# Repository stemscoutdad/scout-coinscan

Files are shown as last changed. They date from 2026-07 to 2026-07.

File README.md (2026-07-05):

SCOUT CoinScan logo

# SCOUT CoinScan

**Sorting Coins Optically with UV Technology** — an open-source coin identification, grading-assist, and sorting machine printed on the Snapmaker U1.

Entered in the **Snapmaker Innovation Fund · Open Competition Phase 1** (June–September 2026).

Repo: https://github.com/stemscoutdad/scout-coinscan

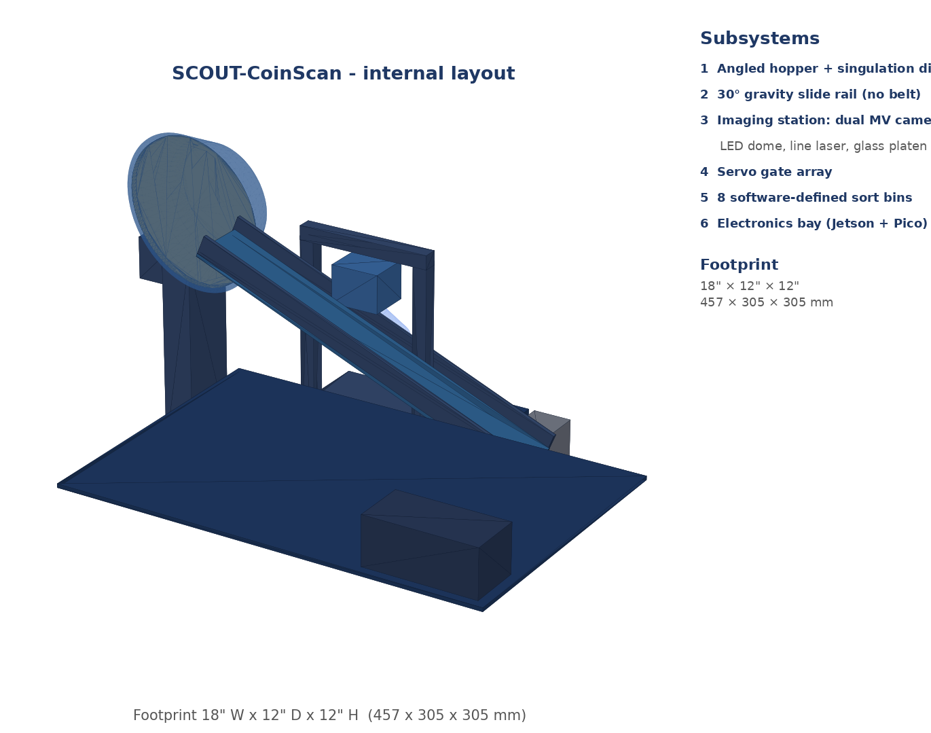
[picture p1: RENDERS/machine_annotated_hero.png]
SCOUT-CoinScan concept rendering


*Concept rendering — 18″ W × 12″ D × 12″ H envelope. Gravity-fed hopper → dual-camera imaging station → software-defined sort bins.*

---

## What it does

Feed it a jar of mixed coins. A U1-printed singulation disk presents one coin at a time onto a gravity slide rail — no conveyor, no belt. Each coin stops on a glass platen between two cameras and is imaged on both faces simultaneously with a multispectral capture sequence: cross-polarized white light, four-direction photometric-stereo sweeps, 470/630/850 nm and 365 nm UV channels, and a swept 650 nm line-laser height profile. On-device ML (NVIDIA Jetson Orin NX 16 GB, 157 TOPS) identifies the coin, reads the date and mint mark, flags doubled dies, repunched marks, silver composition, cleaning and alteration, and estimates a condition-assist score. A servo then steers the coin into one of eight bins.

**The sort is pure software.** Sort by denomination today; by decade, mint mark, or silver content tomorrow — one config change, zero reprinting. The vision system also closes the loop on mechanical singulation: side-by-side double feeds are detected optically and recirculated to the hopper automatically.

## Why the U1 specifically

- **Co-printed TPU-on-PETG mechanisms** — hopper double-wiper, brake brushes, gate-paddle facings, V-stop pads, deflector lip: flexible features printed in place, no assembly.
- **Color as function** — multicolor drop-in calibration target at the coin plane, color-coded bins, translucent diffuser ring on an opaque lighting dome.
- **Bed finish as bearing surface** — rail sections printed face-down so the U1's bed finish becomes the coin's low-friction slide surface.

## Repository layout

```
CAD/        STEP solids + DXF face drawings (disk, platen, brackets, calibration target)
HARDWARE/   Master BOM (sourced part numbers + links), wiring notes
DOCS/       One-pager, Jetson↔Pico protocol spec, build guide (in progress)
FIRMWARE/   RP2040 Pico real-time controller — coming with the July build
SOFTWARE/   Jetson vision pipeline — coming with the July build
```

## Build tiers

| | Flagship | Budget |
|---|---|---|
| Compute | Jetson Orin NX 16 GB dev kit | Jetson Orin Nano Super 8 GB |
| Cameras | 2× 1″ Sony IMX283 20 MP (USB 3.0) | 2× IMX477 HQ 12.3 MP (CSI) |
| Focus | Motorized AF + focus stacking | Fixed focus |
| Est. cost | ~$1,650 | ~$900 |

## Safety

365 nm UV and the line laser are enclosed behind an acrylic-windowed panel with a lid interlock wired in hardware series with both supplies.

## Status

- [x] Architecture, optics geometry, sourced BOM, transport design, control protocol
- [x] Parametric CAD: singulation disk, platen frame, bracket set, calibration target
- [ ] Imaging station build + capture pipeline (July milestone)
- [ ] Transport + gate integration, classifier training (August)
- [ ] Documentation, demo video, release (early September)

## License

MIT — see [LICENSE](LICENSE).

---

*Project lead: Benjamin Flores (Chula Vista, CA) — machining/fabrication, electronics, and numismatics. This build also anchors STEM programming for a local Scouts BSA troop maker initiative. If this project is useful or interesting to you, a ⭐ helps it in the Innovation Fund community vote!*

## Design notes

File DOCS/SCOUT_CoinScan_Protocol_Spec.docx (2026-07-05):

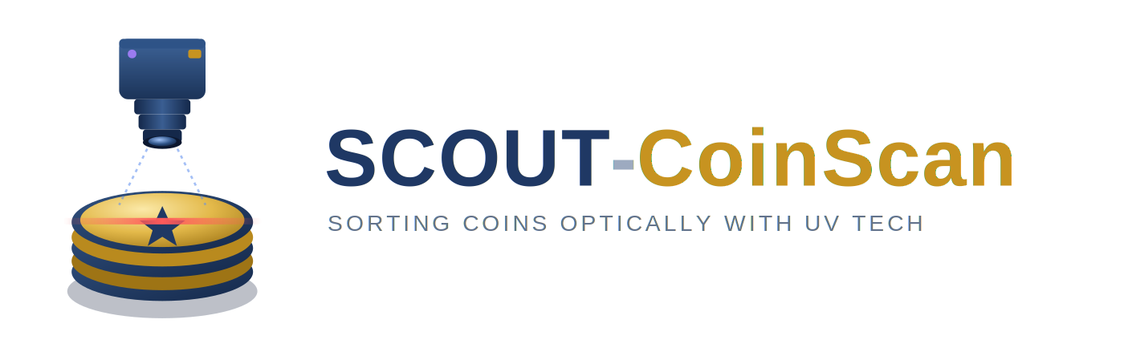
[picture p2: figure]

SCOUT CoinScan — Jetson ↔ Pico Command Protocol

v0.1 · USB CDC serial · 115200 baud 8N1 · ASCII lines terminated \n

The Jetson (host) is the master and issues commands; the RP2040 Pico (controller) executes real-time motion, lighting, and sensor tasks and replies. Fields are space-separated. Every command carries an integer sequence id so replies can be matched.

# Line format

Host → Pico: <seq> <CMD> [args...]

Pico → Host: <seq> OK [data...] // success

<seq> ERR <code> <msg> // failure

EVT <name> [data...] // asynchronous, no seq

The Pico echoes the seq it received. Events (EVT) are unsolicited — beam breaks, faults, interlock trips — and carry no seq.

# Commands

CMD | Args | Action | Reply
PING | — | Liveness check | OK <fw_version>
HOME | — | Home Z-stage, center V-stop, paddles flat | OK when settled
FEED | — | Index singulation disk 90°, present next coin | OK or ERR JAM
ZMOVE | <µm> | Absolute Z-stage move (0 = platen focus datum) | OK <pos_um>
ZSWEEP | <start> <step> <n> | Move + EVT FOCUSPT at each stop for AF | OK after last
LIGHT | <ch> <pct> | Set one lighting channel | OK
CAPSEQ | <preset> | Run stored light sequence; EVT FRAME per state | OK after sequence
LASER | <0|1> | Line laser off/on (interlock-gated) | OK or ERR INTERLOCK
LSWEEP | <deg0> <deg1> <ms> | Pivot laser across coin; EVT LASERPT per step | OK
VSTOP | <0|1> | 0 = hold coin, 1 = retract/release | OK
GATE | <n> <0|1> | Paddle n (1–8): 0 flat, 1 deflect | OK
SORT | <bin> | Set paddle, retract V-stop, watch rail-end beam | OK <bin> or ERR MISS
STATUS | — | Dump sensor + position state | OK <json>
ESTOP | — | All motion halt, laser+UV off, paddles flat | OK

# Lighting channels (LIGHT)

0 white ring · 1 UV 365 nm · 2 blue 470 nm · 3 red 630 nm · 4 IR 850 nm · 5..8 white quadrants N/E/S/W (photometric stereo). pct = 0–100.

# Capture presets (CAPSEQ)

- 1 FAST — cross-polarized white only (bulk sorting)
- 2 FULL — white → quad N/E/S/W → blue → red → IR → UV, EVT FRAME at each (deep scan)
- 3 CALIB — white flat field for px/mm + white balance

# Events

EVT | Data | Meaning
BEAM | <id> <0|1> | Break-beam edge (1 entry, 2 pre-gate, 3 rail-end)
FOCUSPT | <pos_um> | Z-stage settled at sweep stop; host computes sharpness
FRAME | <tag> | Lights set for <tag>; host grabs both cameras now
LASERPT | <deg> | Laser at angle; host grabs top-cam frame
MISS | <bin> | Rail-end beam fired after SORT — coin missed its gate
JAM | <where> | Disk stall or beam-timeout
INTERLOCK | <0|1> | Lid opened (1) / closed (0); laser+UV force-off on open
FAULT | <code> | Driver fault (stepper OT, servo brownout)

# Typical single-coin cycle (host orchestration)

1. FEED — coin lands; EVT BEAM 1 1 fires when it reaches the station
2. VSTOP 0 (hold) — coin self-centers on the V
3. ZSWEEP → collect EVT FOCUSPT, host finds peak, ZMOVE <peak>
4. CAPSEQ 2 FULL → host grabs frame pairs on each EVT FRAME
5. LSWEEP → host builds height map from EVT LASERPT frames
6. Host runs vision → decides bin
7. SORT <bin> → V-stop retracts, coin routes; ERR MISS if rail-end beam trips
8. Paddle auto-returns flat; loop to 1 (next coin already staged)

# Safety invariants (enforced on the Pico, not the host)

- LASER 1 and UV (LIGHT 1 >0) are refused with ERR INTERLOCK whenever the lid switch is open; both are hardware-series-cut regardless.
- Any EVT INTERLOCK 1 immediately zeroes laser + UV channels on the Pico without waiting for the host.
- Watchdog: if no host line for 3 s during motion, the Pico executes ESTOP.

Design intent: the Pico guarantees timing and safety; the Jetson owns all vision and decisions. Keeping the split this clean is what lets each half be released and reused independently.

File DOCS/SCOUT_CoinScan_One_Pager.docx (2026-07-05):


SCOUT CoinScan

Sorting Coins Optically with UV Technology · Snapmaker Innovation Fund · Open Competition Phase 1 · June–September 2026

An open-source, U1-printed machine that identifies, inspects, and sorts coins by what they actually are — not just how big they are.


Concept rendering — 18″ W × 12″ D × 12″ H envelope. Gravity-fed hopper → imaging station → software-defined sort bins.

# What it does

Feed it a jar of mixed coins. A U1-printed singulation disk presents one coin at a time onto a gravity slide rail — no conveyor, no belt. Each coin stops on a glass platen between two cameras and is imaged on both faces simultaneously with a multispectral capture sequence: cross-polarized white light, four-direction photometric-stereo sweeps, 470 nm / 630 nm / 850 nm / 365 nm UV channels, and a swept 650 nm line-laser height profile. On-device ML (NVIDIA Jetson Orin NX 16 GB, 157 TOPS) identifies the coin, reads the date and mint mark, flags doubled dies, repunched marks, silver composition, cleaning and alteration, and estimates a condition-assist score. A servo then steers the coin into one of eight bins.

The sort is pure software. Sort by denomination today; by decade, mint mark, or silver content tomorrow — one config change, zero reprinting. The vision system also closes the loop on mechanical singulation: side-by-side double feeds are detected optically and recirculated to the hopper automatically.

# Why the U1 specifically

Nearly every structural, optical, and mechanical part is printed, and the design leans on the U1's four-toolhead system in ways single-material printers can't reproduce:

- Co-printed TPU-on-PETG mechanisms — hopper double-wiper, brake brushes, gate-paddle facings, V-stop pads, deflector lip: flexible features printed in place, no assembly.
- Color as function — a drop-in camera-calibration target printed in contrasting colors at the coin plane; color-coded bins; translucent diffuser ring on an opaque dome for the lighting module.
- Bed finish as bearing surface — rail sections printed face-down so the U1's bed finish becomes the coin's low-friction slide surface.

# Open-source deliverables

1. Full parametric CAD + STLs/3MFs for every printed part, with print orientation notes
2. Pico real-time firmware and Jetson vision pipeline (capture, classification, OCR, photometric stereo, laser profilometry)
3. Standalone reusable module: the multispectral inspection light — addressable, polarized, five-wavelength LED dome with printed diffuser, useful for any small-object inspection project
4. Documented budget build (Jetson Orin Nano 8 GB + dual IMX477, fixed focus, ~$900) alongside the flagship build (Orin NX 16 GB developer kit + dual 1″ IMX283 20 MP cameras + motorized focus-stacking stage, ~$1,650)
5. Build guide, calibration procedure, and a U1 multi-material design write-up covering the co-printing techniques used

# Technical depth highlights

- Photometric-stereo relief mapping for die-variety and error detection on a hobby-class budget
- UV-fluorescence detection of cleaning, PVC residue, and altered surfaces
- Laser-triangulation thickness/edge profiling as a third biometric against slugs and counterfeits
- Two-tier adaptive capture: fast pass for bulk, deep scan (focus stack + full spectral sequence) auto-triggered for coins the classifier flags as interesting
- Pre-positioned gate control: identification happens while the coin is parked, so every sort is a static ramp by the time the coin moves — one sensor detects any miss

# Safety

365 nm UV and the line laser are enclosed behind an acrylic-windowed panel with a lid interlock wired in hardware series with both supplies.

# Status & timeline (Phase 1)

- Now: architecture, optics geometry, full BOM with sourced part numbers, and transport design complete
- July: imaging station build + capture pipeline (standalone demo milestone)
- August: hopper/transport integration, gate array, classification training
- Early September: documentation, demo video, community release

Designed so each stage stands alone as a working, documented deliverable.

# The ask

We're requesting a sponsored U1 to develop and debug on — the design's co-printed TPU mechanisms and multicolor functional parts need on-machine iteration to tune. Project lead: Benjamin Flores (Chula Vista, CA) — machining/fabrication, electronics, and numismatics background; the project also anchors STEM programming for a local Scouts BSA troop's maker initiative.

Repo: https://github.com/stemscoutdad/scout-coinscan · Demo video: [link] · Discussion: Snapmaker forum thread [link]

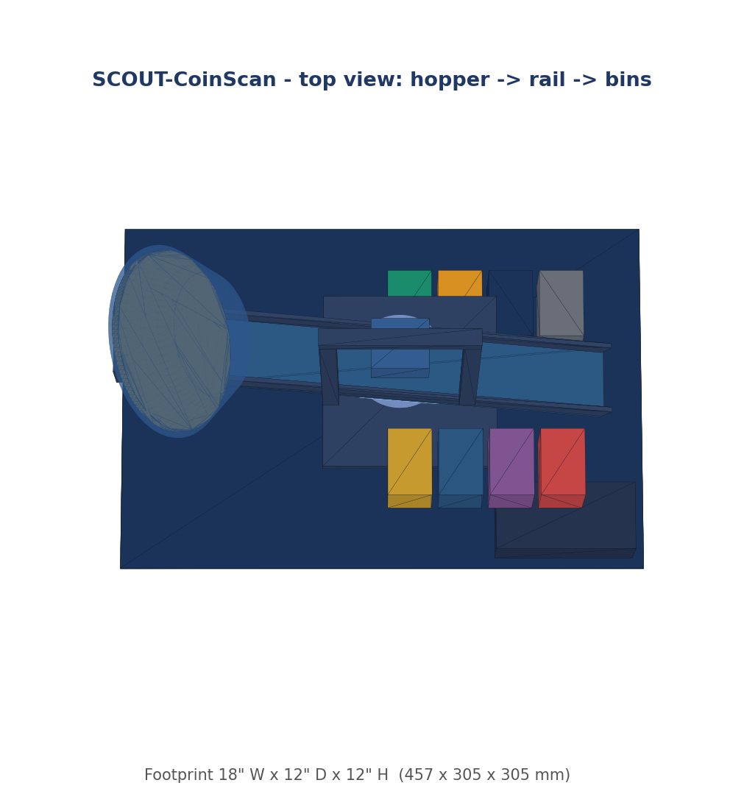
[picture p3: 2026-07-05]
RENDERS/machine_open_top.png

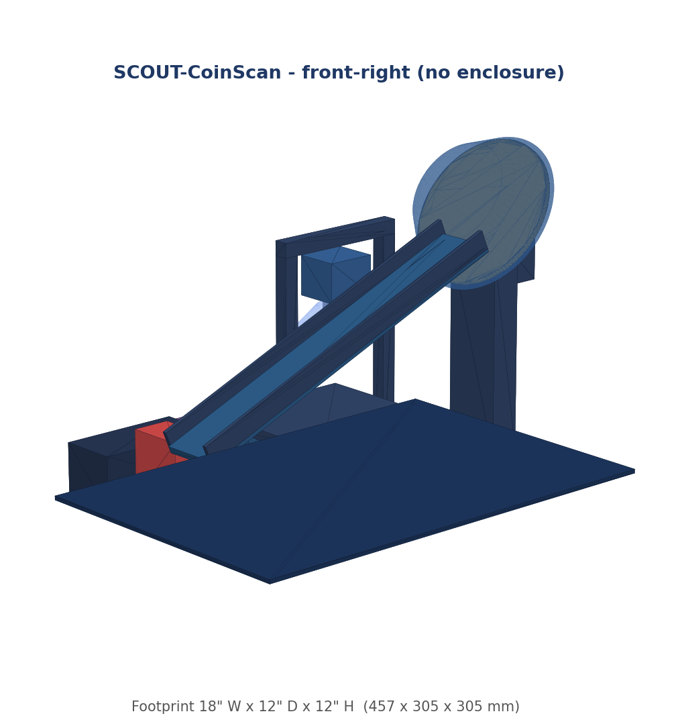
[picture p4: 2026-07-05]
RENDERS/machine_open_front.png

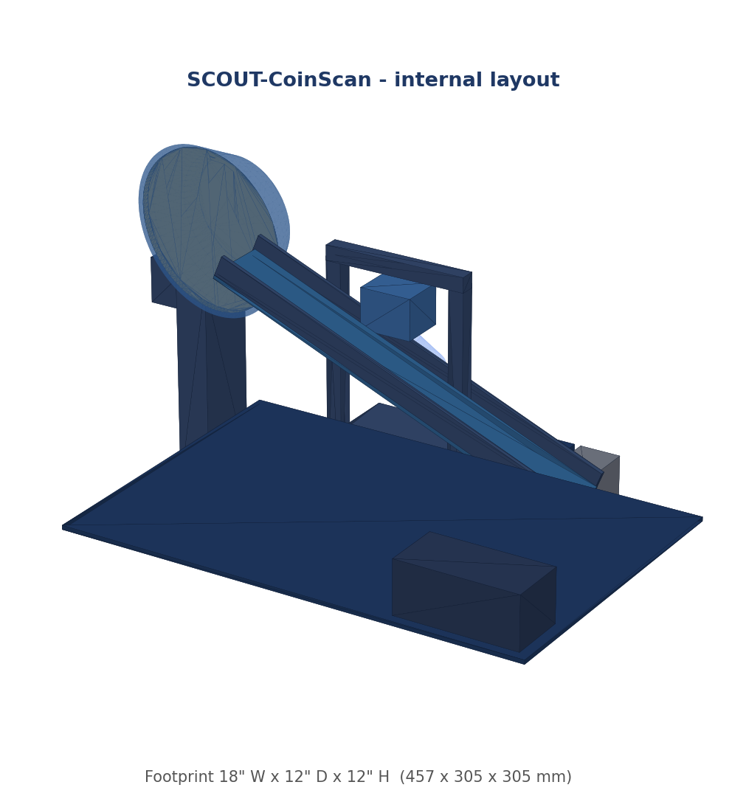
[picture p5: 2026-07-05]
RENDERS/machine_open_hero.png

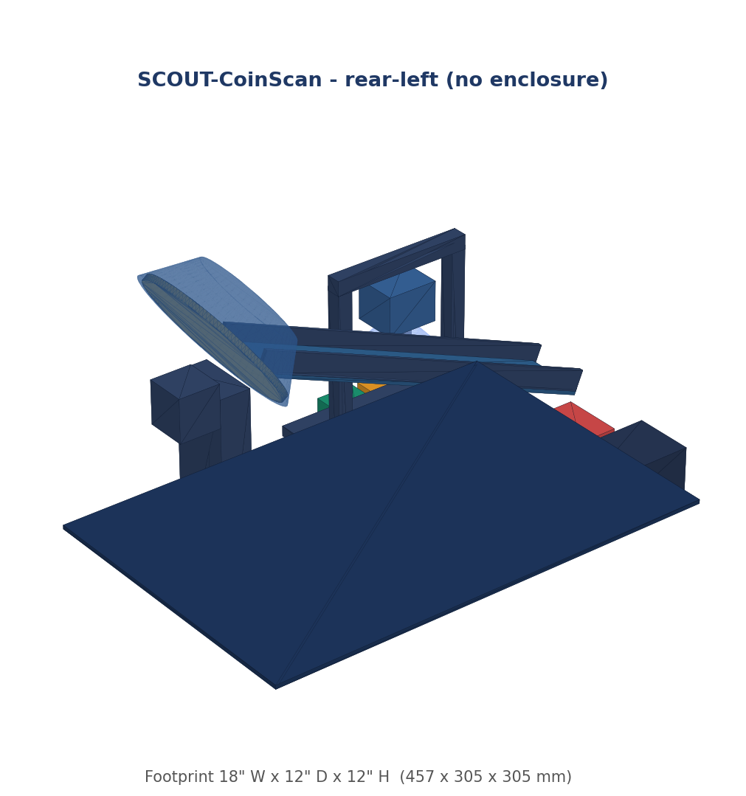
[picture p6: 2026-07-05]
RENDERS/machine_open_rear.png

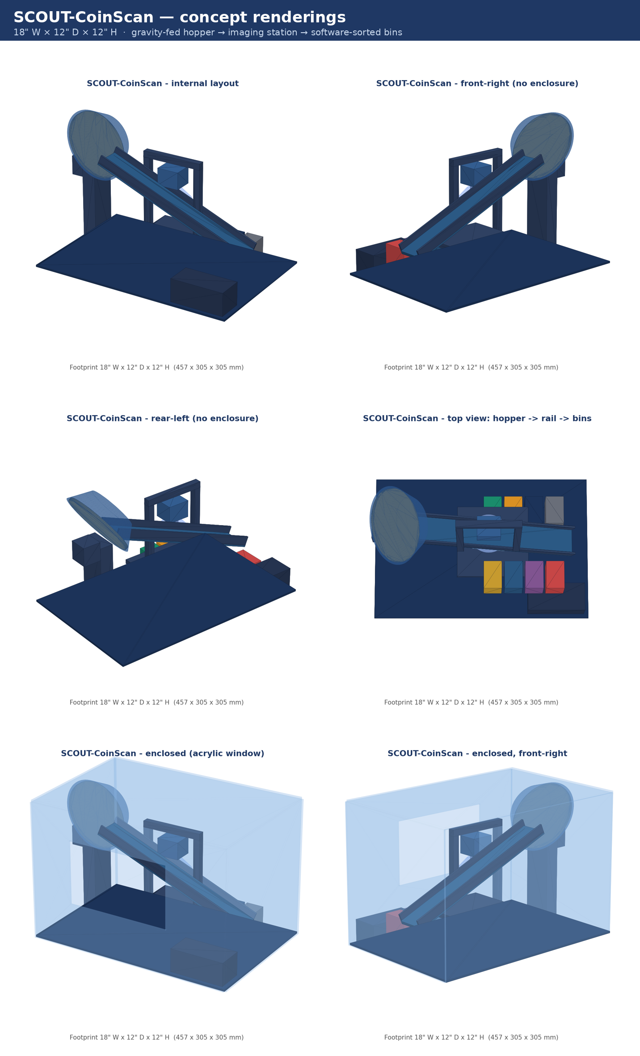
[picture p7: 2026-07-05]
RENDERS/machine_contact_sheet.png

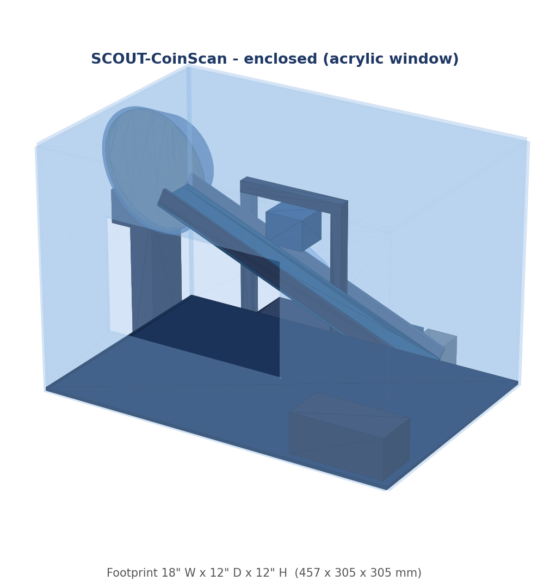
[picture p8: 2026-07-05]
RENDERS/machine_enclosed_hero.png

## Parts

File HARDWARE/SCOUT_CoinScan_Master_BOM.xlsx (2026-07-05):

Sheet: Master BOM
SCOUT CoinScan — Master Bill of Materials (Snapmaker Innovation Fund, Phase 1 · 2026)
Item | Part No. / SKU | Source link | Spec / Notes | Qty | Unit $ | Ext. Flagship | Ext. Budget | Flag | Budg | Vendor
COMPUTE & CONTROL
Yahboom Jetson Orin NX Super Developer Kit 16GB | Orin NX 16GB · Developer Kit tier | https://category.yahboom.net/products/jetson-orin-nx | FLAGSHIP compute: NVIDIA Orin NX 16GB core module on Yahboom carrier; 157 TOPS; incl. 256GB SSD preloaded + WiFi + PSU; dual CSI. VERIFY at order: 15- vs 22-pin CSI ribbon for IMX477, and IMX477 overlay on Yahboom image (their docs center on IMX219) | 1 | $789.00 | $789.00 | $0.00 | Y | — | Yahboom / RobotShop / Amazon
NVIDIA Jetson Orin Nano Super Dev Kit 8GB | 945-13766-0000-000 | https://marketplace.nvidia.com/en-us/enterprise/robotics-edge/jetson-orin-nano-super-developer-kit/ | BUDGET compute (8GB — no 16GB Nano kit exists); dual IMX477 on both official MIPI ports | 1 | $249.00 | $0.00 | $249.00 | — | Y | NVIDIA / Arrow / Newegg
Raspberry Pi Pico (RP2040) | SC0915 | https://www.raspberrypi.com/products/raspberry-pi-pico/ | Real-time I/O: servos, LEDs, laser, beams | 1 | $5.00 | $5.00 | $5.00 | Y | Y | PiShop / Adafruit
NVMe SSD 500GB M.2 2280 | (any; e.g. WD SN570) | https://www.westerndigital.com/ | BUDGET boot/archive (flagship Yahboom kit includes preloaded 256GB; upgrade optional) | 1 | $45.00 | $0.00 | $45.00 | — | Y | Amazon / Newegg
5V 10A PSU + buck converters | (generic; e.g. Pololu D24V) | https://www.pololu.com/category/76/step-down-voltage-regulators | LED/servo/logic rail; separate from compute | 1 | $25.00 | $25.00 | $25.00 | Y | Y | Amazon / Pololu
IMAGING
Arducam IMX283 1" 20MP USB 3.0 (16mm C-mount) ×2 | B0477 | https://www.arducam.com/blog/product/arducam-20mp-usb-3-0-camera-module-with-16mm-c-mount-lens-b0477/ | FLAGSHIP top + bottom: identical 1" IMX283 sensors + 16mm lenses over USB 3.2 — works on Yahboom carrier (xISP MIPI Klarity is limited to ONE port and official carrier only, so USB3 is the supported dual-IMX283 path) | 2 | $199.00 | $398.00 | $0.00 | Y | — | Arducam / Amazon B0CW1PTSCB
Arducam IMX477 HQ 12.3MP (C/CS-mount) ×2 | B0242 | https://www.arducam.com/b0242-arducam-imx477-hq-camera.html | BUDGET top + bottom: natively adapted on BOTH Orin Nano MIPI ports | 2 | $70.00 | $0.00 | $140.00 | — | Y | Arducam
25mm C-mount MV lens f/1.4 | (generic MV; e.g. Arducam LN059) | https://www.arducam.com/product-category/accessories/lenses/ | Budget top optics; stop to f/8; WD≈153mm (flagship uses included 16mm lenses) | 1 | $45.00 | $0.00 | $45.00 | — | Y | Arducam / AliExpress
12mm CS/C-mount lens | (generic; e.g. Arducam LN060) | https://www.arducam.com/product-category/accessories/lenses/ | Budget bottom cam; WD≈127mm | 1 | $25.00 | $0.00 | $25.00 | — | Y | Arducam
C-mount extension/spacer tube kit | (generic C-mount shim set) | https://www.edmundoptics.com/ | 5–10mm spacers to hit m=0.20 | 1 | $12.00 | $12.00 | $12.00 | Y | Y | Amazon / Edmund
Linear polarizer film (2× A5) | (generic; e.g. API film) | https://www.edmundoptics.com/c/polarizers/ | Cross-polarization: LED rings + lens analyzer rings | 1 | $12.00 | $12.00 | $12.00 | Y | Y | Edmund / Amazon
AR-coated glass platen 100×100mm | (generic AR window) | https://www.edmundoptics.com/c/windows/ | Imaging window; AR both sides | 1 | $20.00 | $20.00 | $20.00 | Y | Y | Edmund / eBay optics
LIGHTING & SPECTRAL
Addressable RGBW LED ring 24px (×2) | Adafruit 2874 | https://www.adafruit.com/product/2874 | Photometric-stereo quadrant sweep, top & bottom | 2 | $17.00 | $34.00 | $34.00 | Y | Y | Adafruit
365nm true-UV LED + MOSFET driver (×2) | (365nm; e.g. LED Engin LZ1) | https://www.ledsupply.com/leds/uv-ultraviolet-power-leds | Fluorescence; NOT 395nm blacklight | 2 | $9.00 | $18.00 | $18.00 | Y | Y | LED Supply / Digi-Key
850nm IR LED cluster (×2) | (generic 850nm) | https://www.digikey.com/ | Toning/corrosion penetration channel | 2 | $4.00 | $8.00 | $8.00 | Y | Y | Amazon / Digi-Key
470nm blue + 630nm red 3W LEDs | (generic star LEDs) | https://www.ledsupply.com/ | Composition ratio channels | 4 | $2.50 | $10.00 | $10.00 | Y | Y | LED Supply / Digi-Key
650nm line laser <5mW + pivot micro servo | (generic Class IIIa line) | https://www.adafruit.com/product/1057 | Profilometry sweep; interlock via lid switch | 1 | $14.00 | $14.00 | $14.00 | Y | Y | Amazon / Adafruit
Logic-level MOSFET driver 4ch (×2) | (generic; e.g. IRF520 board) | https://www.sparkfun.com/ | UV/IR/blue/red current drive from Pico | 2 | $6.00 | $12.00 | $12.00 | Y | Y | Amazon / SparkFun
MOTION — AUTOFOCUS STAGE (flagship)
MGN9 miniature rail 55mm + carriage | MGN9H-55 | https://www.amazon.com/ | Top camera Z-stage guide | 1 | $9.00 | $9.00 | $0.00 | Y | — | Amazon / AliExpress
NEMA11 stepper + M3×0.5 lead screw 60mm | (11HS + Tr/M3) | https://www.omc-stepperonline.com/nema-11-stepper-motor | 0.156µm/µstep @16×; printed anti-backlash nut | 1 | $18.00 | $18.00 | $0.00 | Y | — | StepperOnline
TMC2208 stepper driver (Z-stage) | BTT TMC2208 v3 | https://biqu.equipment/products/bigtreetech-tmc2208-v3-0 | Silent; driven from Pico | 1 | $6.00 | $6.00 | $0.00 | Y | — | BIQU / Amazon
Optical endstop | (generic opto endstop) | https://www.amazon.com/ | Z-stage homing | 1 | $3.00 | $3.00 | $0.00 | Y | — | Amazon
MOTION — TRANSPORT & SORTING
NEMA17 stepper + TMC2208 (disk) | 17HS + TMC2208 | https://www.omc-stepperonline.com/nema-17-stepper-motor | Hopper/disk drive | 1 | $16.00 | $16.00 | $16.00 | Y | Y | StepperOnline
MG90S metal-gear micro servos | MG90S | https://www.adafruit.com/product/1143 | 8 gate paddles + V-stop + laser pivot (=10) | 10 | $4.00 | $40.00 | $40.00 | Y | Y | Amazon / Adafruit
PCA9685 16-ch PWM driver | Adafruit 815 | https://www.adafruit.com/product/815 | Servo fan-out from Pico I²C | 1 | $6.00 | $6.00 | $6.00 | Y | Y | Adafruit
IR break-beam sensor pairs | Adafruit 2168 | https://www.adafruit.com/product/2168 | Station entry + jam + rail-end miss detect | 3 | $3.00 | $9.00 | $9.00 | Y | Y | Adafruit
Lid interlock microswitch | (generic SPDT) | https://www.digikey.com/ | Series-kills laser + UV when case open | 1 | $2.00 | $2.00 | $2.00 | Y | Y | Amazon / Digi-Key
STRUCTURE & CONSUMABLES (U1-PRINTED + HW)
2020 aluminum extrusion 600mm (×2) | 2020-600 | https://www.amazon.com/ | Vibration-damping backbone for rail | 2 | $8.00 | $16.00 | $16.00 | Y | Y | Amazon / Misumi
PETG filament (structure/bins/dome) | Snapmaker PETG | https://us.snapmaker.com/products/snapmaker-petg-filament | ~2.5kg across printed parts | 3 | $20.00 | $60.00 | $60.00 | Y | Y | Snapmaker store
TPU filament (pockets/flappers/dampers) | Snapmaker TPU | https://us.snapmaker.com/ | Co-printed flexible features | 1 | $25.00 | $25.00 | $25.00 | Y | Y | Snapmaker store
PLA multicolor (bins/fiducials/badges) | Snapmaker PLA | https://us.snapmaker.com/ | U1 multicolor showcase parts | 1 | $20.00 | $20.00 | $20.00 | Y | Y | Snapmaker store
M3 hardware kit + heat-set inserts | (generic M3 + brass inserts) | https://www.mcmaster.com/ | Assembly fasteners | 1 | $15.00 | $15.00 | $15.00 | Y | Y | McMaster / Amazon
608 bearings ×4, springs, misc | 608-2RS | https://www.mcmaster.com/ | Disk hub, nut preload, gate returns | 1 | $10.00 | $10.00 | $10.00 | Y | Y | Amazon / McMaster
Wiring, JST kit, heatshrink, ferrules | (generic) | https://www.amazon.com/ | Harness | 1 | $15.00 | $15.00 | $15.00 | Y | Y | Amazon
 |  |  | TOTAL (estimated) |  |  | $1627 | $908
Notes: Blue unit prices = editable (Jul 2026 estimates). Blue links open vendor pages. Verified SKUs: Jetson 945-13766-0000-000, Klarity IMX283 B0542, IMX283 USB B0477, IMX477 HQ B0242, Adafruit parts by product ID. Lines marked (generic)/(any) = representative — confirm exact SKU at purchase. Flagship = Yahboom Orin NX Super Dev Kit 16GB + dual 1" IMX283 USB3 + motorized AF stage. Budget = Orin Nano 8GB kit + dual IMX477 MIPI, fixed focus. Note: no 16GB Orin Nano dev kit exists — 8GB only. U1 printer excluded.

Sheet: Optics & Stages
Imaging Geometry & Focus-Stage Specs
Parameter | Top — Flagship (IMX283 USB3) | Bottom — Flagship (IMX283 USB3) | Top — Budget (IMX477) | Bottom — Budget (IMX477) | Notes
Sensor / active area | 1" · 13.2 × 8.8 mm | 1" · 13.2 × 8.8 mm | 1/2.3" · 6.29 × 4.71 mm | 1/2.3" · 6.29 × 4.71 mm | Identical 1-inch sensors both faces (flagship)
Connection | USB 3.2 (UVC) | USB 3.2 (UVC) | MIPI CSI-0 | MIPI CSI-1 | USB3 works on Yahboom carrier; xISP MIPI = 1 port, official carrier only
Resolution / pixel | 5472×3648 · 2.4 µm | 5472×3648 · 2.4 µm | 4056×3040 · 1.55 µm | 4056×3040 · 1.55 µm | Big pixels feed UV channel
Field of view | 45 mm | 45 mm | 45 mm | 45 mm | Morgan 38.1 mm + margin
Magnification m | 0.196 | 0.196 | 0.105 | 0.105 | m = sensor short axis / FOV
Sampling | ~82 px/mm | ~82 px/mm | ~68 px/mm | ~68 px/mm | Mint mark ≈1 mm
Lens | 16 mm C (included) | 16 mm C (included) | 25 mm C + ext. | 12 mm CS/C | Manual iris
Working distance | ≈98 mm | ≈98 mm | ≈153 mm | ≈127 mm | WD ≈ f(1+1/m)
Aperture | f/5.6 | f/5.6 | f/8 | f/5.6 | Budget top stops down for DOF
Depth of field | ≈1.7 mm | n/a (const. distance) | ≈3.5 mm @f/8 | n/a (const. distance) | Flagship top DOF is why the AF stage matters
Focus scheme | Motorized AF + 5-frame stack | Fixed, locked at platen | Fixed collar @ median +2mm | Fixed, locked at platen | Bottom always fixed
Stage / drive | 10mm · NEMA11 + M3×0.5 | — | — | — | 0.156µm/µstep @16×
Camera assignment rationale: the flagship runs two identical 1" IMX283 USB 3.0 cameras (B0477) — the only supported way to get dual IMX283 on one board, since the xISP Klarity MIPI (B0542) supports a single camera port and requires the official NVIDIA carrier (the Yahboom carrier is third-party). The budget build runs dual IMX477 on both official Orin Nano MIPI ports, a fully supported native config.

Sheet: Coin Reference
US Coin Dimensions — Design Envelope
Coin | Diameter (mm) | Thickness (mm) | Mass (g) | Composition (common) | Sorting note
Dime | 17.91 | 1.35 | 2.27 | Cu-Ni clad (90% Ag pre-1965) | Smallest — sets pocket min
Penny (Cent) | 19.05 | 1.52 | 2.50 | Zn core Cu-plated (bronze pre-1982) | Blue channel splits bronze/zinc
Nickel | 21.21 | 1.95 | 5.00 | 75/25 Cu-Ni (35% Ag war 42–45) | War nickels flagged spectrally
Quarter | 24.26 | 1.75 | 5.67 | Cu-Ni clad (90% Ag pre-1965) | 2.24mm below golden $
Golden dollar (SBA/Sac) | 26.50 | 2.00 | 8.10 | Manganese-brass clad | Camera verifies vs quarter
Half dollar (Kennedy) | 30.61 | 2.15 | 11.34 | Clad (40% Ag 65–70, 90% pre-65) | Spectral silver check
Morgan / Peace / Ike dollar | 38.10 | 2.90 | 26.73 | 90% Ag (Morgan/Peace); Ike clad | Largest — sets FOV & pocket max
Design envelope: Ø 17.91–38.1 mm · thickness 1.35–2.9 mm · top-surface height variation 1.55 mm (drives AF stage).

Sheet: Transport Parts
Transport Assembly — Printed & Hardware Parts (Hopper · Rail · Servo Gate Array)
Part | Qty | Material | Print orientation / method | Key dims | Design notes
HOPPER / SINGULATION
Singulation disk | 1 | PETG | Face-down, flat on bed | Ø180 × 3.4 mm, 4× Ø40.5 pockets @ r60 | Through-pockets; agitator ribs; GT2 boss; depth = disk thickness
Backplate | 1 | PETG | Face-down, flat on bed | Ø190 × 4 mm; 41×41 exit window @ 12 o'clock | 0.4–0.5mm gap to disk; window 8mm above rail; 45° chamfer
Backplate shim set | 1 | PETG | Flat | 0.2/0.3/0.4/0.5 mm rings | Dial disk gap; dime must not knife behind disk
Exit-window wear insert | 2 | PETG (brass upgrade) | Flat, perimeter walls | Snap-in 41×41 frame | Highest-wear part; print spares
TPU deflector lip | 1 | TPU co-print | On wear insert | 40×12 mm flap | Leans falling coin onto 30° rail face-down
TPU double-wiper finger | 1 | TPU + PETG | Co-printed, flat | 32×13 mm, 1mm proud | Brushes stacked coins back to pool
Hopper bowl | 1 | PETG | Upright, sections | ~1 L; walls ≥50° | Feeds pool in bottom quadrant
Disk drive mount + GT2 3:1 | 1 | PETG | Flat plates | NEMA17, 20T→60T | Index 90°/feed; stall-detect; reverse-retry
RAIL — APPROACH & IMAGING
Approach rail section | 1 | PETG | FACE-DOWN — bed finish = slide surface | 120 mm; walls 45→42 mm | Plain 30° plane; taper centers diameters
Settling-zone brush insert | 1 | TPU + PETG | Co-printed comb | first 40 mm after drop | Kills landing wobble
Brake brush insert | 1 | TPU + PETG | Co-printed comb | last 30 mm before platen | Bleeds ~1 m/s to crawl at V-stop
Platen frame | 1 | PETG multicolor | Face-down | 100×100 glass recess; fiducials + gray patch | Glass flush; px/mm calibration
V-stop + servo horn | 1 | PETG + TPU pads | Flat; pads co-printed | 90° V, TPU-faced | Self-centers Ø17.9–38.1; MG90S retract
GATE RAIL — SOFTWARE-DEFINED SORTING (×8)
Gate rail sections (×2, dovetailed) | 2 | PETG | FACE-DOWN, dovetail | ~420 mm; 8 stations @ 50mm | St.1 recirc/review; 2–8 software bins
Deflector paddle module | 8 | PETG + TPU face | Flat; hinge vertical; face co-print | Full width; ~45° across path | Coin steered by momentum; servo positions
Bin chute | 8 | PETG | Face-down | Ramp → bin; 41mm opening | Passes all coins
Rail-end break-beam mount | 1 | PETG | Flat | IR pair across rail end | Only gate sensor: fires = miss → flag/pause
Recirculation return chute | 1 | PETG | 2 sections, face-down | St.1 → hopper bowl | Doubles + low-confidence loop
Denomination bins | 8 | PLA multicolor | Upright | 7 sort + review, color-coded | Software-defined: denom/decade/mint/silver
Frame / legs + extrusion brackets | 1 | PETG on 2020 extrusion | Sections, flat | Sets single 30° plane | Extrusion damps vibration; T-nut adjust
Control sequence: identify at V-stop → pre-set target paddle → retract V-stop → coin slides over flat gates to deflected paddle → bin. One paddle moves per coin; rail-end beam is sole miss detector. Next coin stages on upper rail during capture.

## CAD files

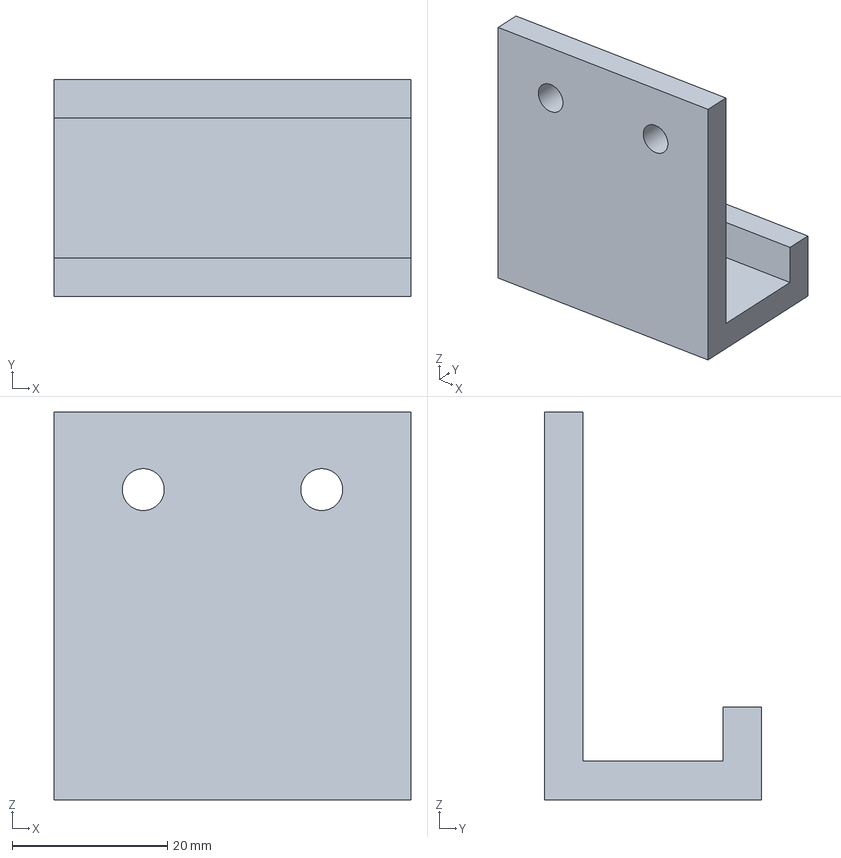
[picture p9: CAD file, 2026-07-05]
CAD/bin_hanger.step
46.0 x 28.0 x 50.0 mm

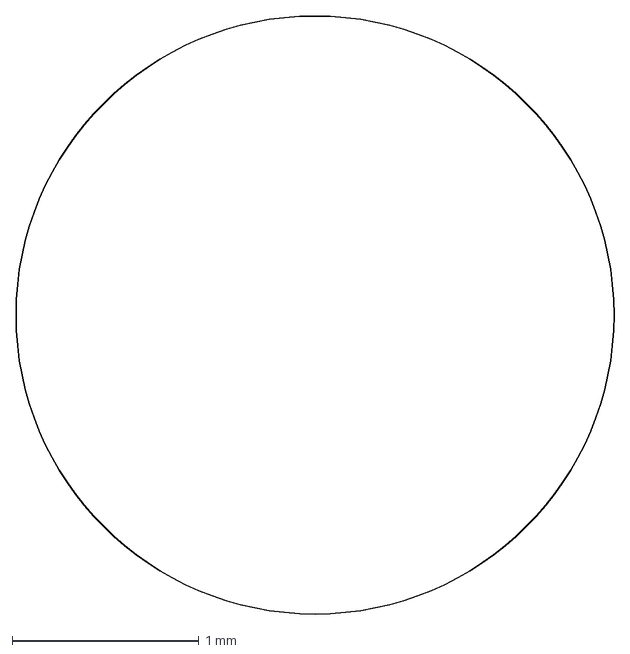
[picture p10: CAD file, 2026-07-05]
CAD/platen_frame_face.dxf
3.20 x 3.20 mm

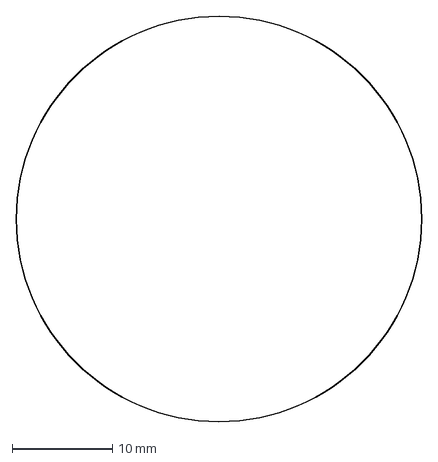
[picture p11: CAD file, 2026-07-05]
CAD/singulation_disk_face.dxf
40.5 x 40.5 mm

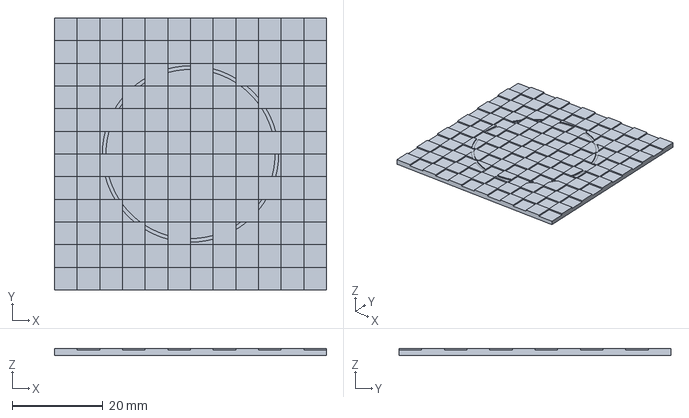
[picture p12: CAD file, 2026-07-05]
CAD/calibration_target.step
60.0 x 60.0 x 1.60 mm

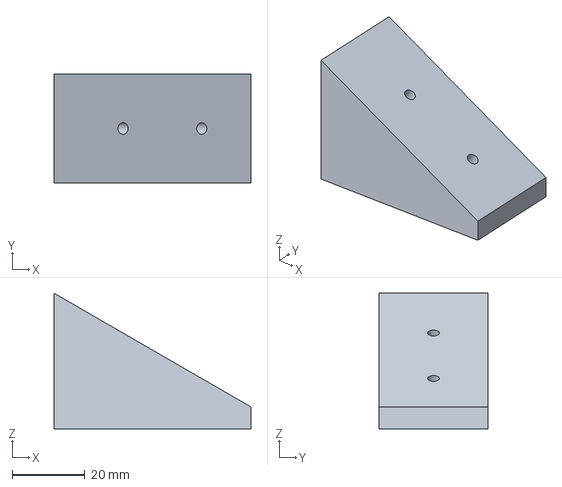
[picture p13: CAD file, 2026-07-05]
CAD/rail_saddle.step
54.0 x 30.0 x 37.2 mm

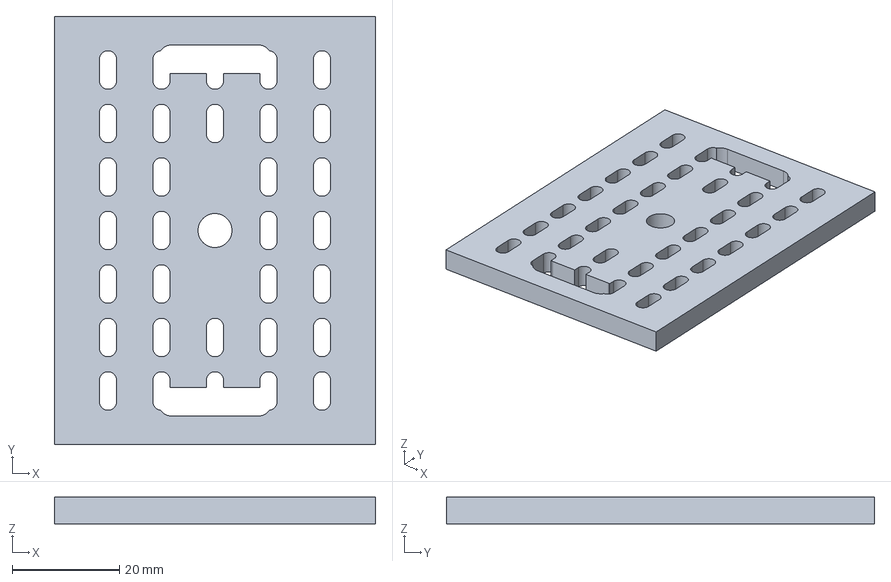
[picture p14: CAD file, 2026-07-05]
CAD/camera_plate.step
60.0 x 80.0 x 5.00 mm

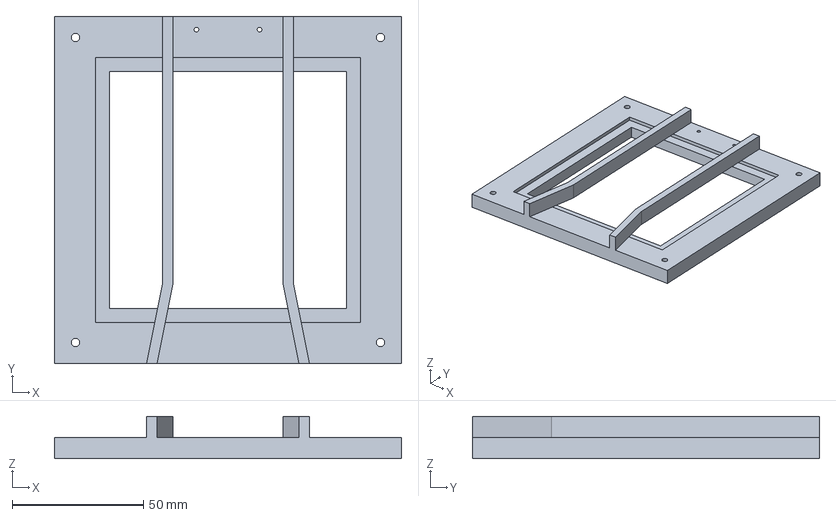
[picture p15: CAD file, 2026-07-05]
CAD/platen_frame.step
132.0 x 132.0 x 16.0 mm

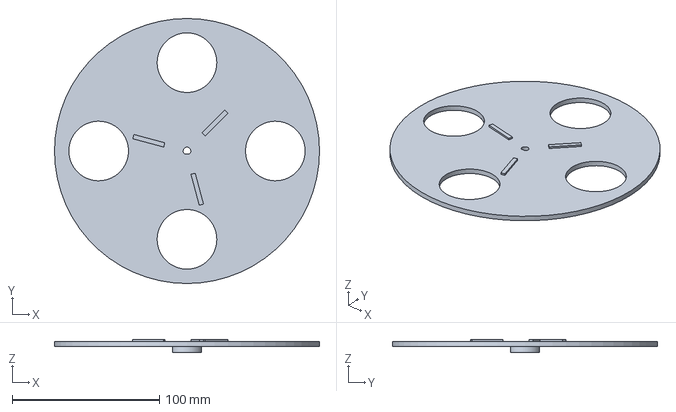
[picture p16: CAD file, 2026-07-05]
CAD/singulation_disk.step
180.0 x 180.0 x 8.60 mm
